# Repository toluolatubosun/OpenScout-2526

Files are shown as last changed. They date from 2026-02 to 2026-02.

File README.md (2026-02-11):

# OpenScout v1.2

OpenScout v1.2 presents an enhanced implementation of the OpenScout mobile robot platform, featuring a novel multi-modal control architecture that integrates conventional wireless control with ROS 2 infrastructure. The system employs a dual-microcontroller architecture utilizing Arduino GIGA R1 WiFi and Arduino Uno, providing three independent control interfaces: HC-12 long-range wireless keypad (100m range),
USB serial interface, and ROS 2 integration via TCP/JSON bridge. A
key innovation is the implementation of a lightweight TCP server on the
Arduino GIGA that enables ROS 2 Twist message compatibility without requiring ros_serial, addressing the compatibility gap in ROS 2 for
resource-constrained embedded systems. The platform incorporates realtime obstacle detection using four ultrasonic sensors with 50cm threshold triggering and buzzer warning with automatic motion prevention.
FreeRTOS task scheduling enables concurrent execution of motor control, network communication, and sensor processing. Quantitative evaluation demonstrates successful multi-modal operation with network latency under 100ms and reliable obstacle detection. This work provides a
reproducible, open-source educational platform bridging embedded systems and modern robotics middleware, licensed under CERN-OHL-S2.0, with complete build documentation enabling 6–20 hour assembly by
non-specialists.

## Demo video can be found in the base of the repository: [Demonstration Video](Demonstration%20Video.mp4)
| | |
|--|--|
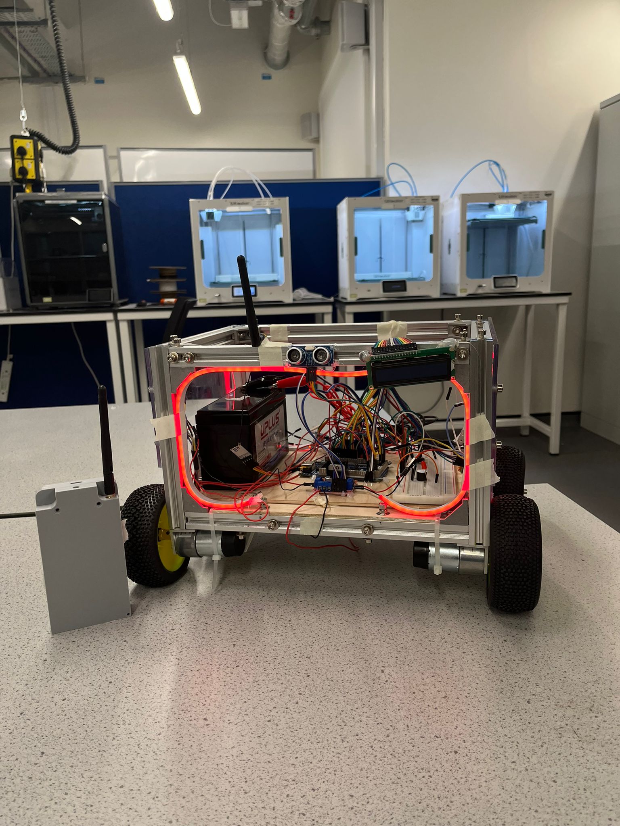
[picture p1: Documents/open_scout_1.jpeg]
OpenScout Robot View 1
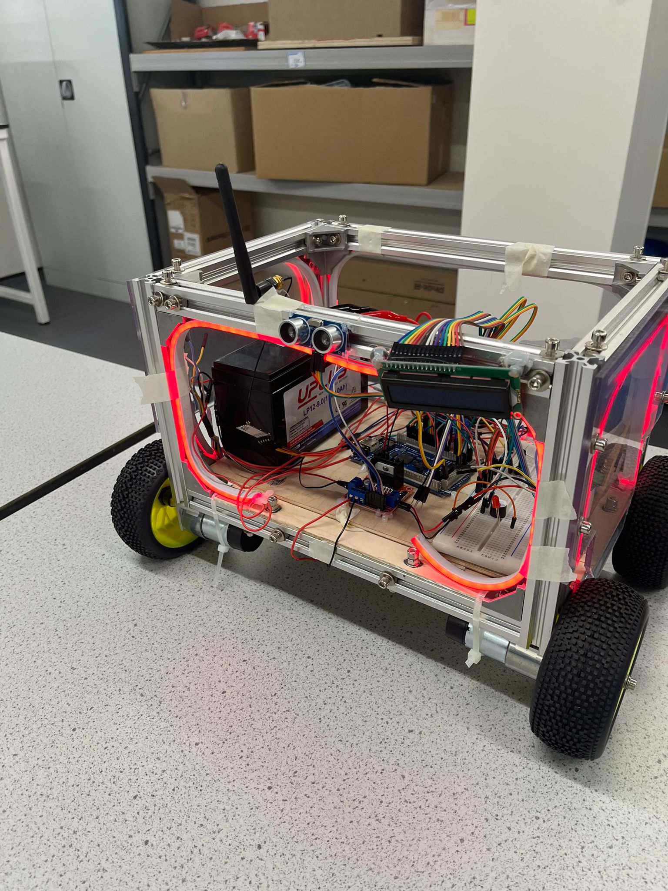
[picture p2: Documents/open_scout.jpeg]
OpenScout Robot View 2
|  |  |
---

## Table of Contents

1. [General Info](#1-general-info)
2. [Build Materials](#2-build-materials)
3. [Mechanical Assembly](#3-mechanical-assembly)
4. [Electric Circuit & Firmware](#4-electric-circuit--firmware)
5. [Testing](#5-testing)
6. [Contributors](#6-contributors) 
7. [Demonstration Video](#7-demonstration-video) 

### 1. General Info 

I. OpenScout V2 & ROS 2 Integration

OpenScout V2 is an enhanced mobile robot platform designed to bridge embedded systems and ROS 2 for accessible robotics education. The system integrates low-level microcontroller-based control with high-level Robot Operating System 2 (ROS 2) infrastructure, enabling both manual and autonomous operation. The platform emphasizes modularity, low cost, and compatibility with resource-constrained embedded hardware.

The robot employs a dual-microcontroller architecture consisting of an Arduino GIGA R1 WiFi and an Arduino Uno. This architecture allows separation of concerns between real-time motor control, sensor processing, and high-level communication with ROS 2. OpenScout V2 supports multiple control interfaces, including wireless, USB serial, and ROS 2-based control.

II. Software Description

OpenScout V2 uses a hybrid software stack combining embedded firmware and ROS 2 middleware. ROS 2 serves as the high-level communication and control framework, while the microcontrollers handle low-level actuation and sensing tasks. ROS 2 operates as a distributed middleware system based on publish–subscribe communication. Motion commands are transmitted as standard ROS 2 messages over a TCP/IP network, allowing seamless integration with existing ROS 2 tools and algorithms. A key design contribution of OpenScout V2 is the implementation of a lightweight TCP/JSON bridge, enabling ROS 2 communication without relying on ros_serial, which is not fully compatible with ROS 2 on constrained embedded platforms.

a). Motion Control

OpenScout V2 is a differential-drive mobile robot. High-level motion commands are expressed using the standard ROS 2 Twist message type, which includes linear and angular velocity components.The Arduino GIGA R1 WiFi hosts a custom TCP server that receives serialized Twist commands from ROS 2 and converts them into motor control signals. These commands are forwarded to the Arduino Uno, which directly controls the motor drivers. This separation ensures real-time responsiveness while maintaining ROS 2 compatibility.

b). Teleoperation Modes

The platform supports multiple manual control modes:

* Wireless keypad control using an HC-12 long-range wireless module (up to 100 m range)

* USB serial control for direct wired operation

* ROS 2 teleoperation, where motion commands are generated from standard ROS 2 tools

>> These interfaces operate independently, enabling flexible switching between control modes for testing, education, and deployment.

c). Sensors and Obstacle Detection

OpenScout V2 is equipped with four ultrasonic distance sensors mounted around the robot chassis. These sensors provide real-time obstacle detection with a configurable threshold (default set to 50 cm).

When an obstacle is detected within the threshold:

* A buzzer warning is triggered

* Robot motion is automatically inhibited to prevent collisions

>>Sensor processing is handled locally on the microcontroller to ensure fast response times independent of ROS 2 network latency.

d). Real-Time Embedded Scheduling

The embedded software stack uses FreeRTOS to manage concurrent tasks on the Arduino GIGA R1 WiFi. Separate tasks are assigned for:

* Motor control

* Network communication (TCP server)

* Sensor acquisition and obstacle detection

>>This task-based scheduling ensures reliable real-time performance and prevents blocking behavior during communication or sensing operations.

e). ROS 2 Communication Interface

Instead of using ros_serial, OpenScout V2 implements a custom TCP-based communication layer. The Arduino GIGA R1 WiFi runs a lightweight TCP server that:

* Receives ROS 2 Twist messages encoded in JSON

* Decodes and validates incoming commands

* Forwards control signals to the motor controller

>>This approach reduces system complexity and improves compatibility with ROS 2, while maintaining low communication latency (measured under 100 ms in evaluation).

---
---
### 2. Build Materials

| Material/Components | Quantity | Reference/Description | Link |
| --- | --- | --- | --- |
| 300 mm 20×20 Aluminium Extrusion | 4 | A1 | [Link](https://ooznest.co.uk/product/v-slot-linear-rail-20x20mm-cut-to-size/) |
| 200 mm 20×20 Aluminium Extrusion | 8 | A2 | [Link](https://ooznest.co.uk/product/v-slot-linear-rail-20x20mm-cut-to-size/) |
| 20×20 Angle Joint Brackets | 16 | B1 | [Link](https://amz.run/5TF6) |
| 90° Cast Corner Brackets | 8 | B2 | [Link](https://ooznest.co.uk/product/90-degree-cast-corner/) |
| M5 × 12 mm Hex Socket Screws | 72 | S5.12 | – |
| M4 T-Slot Nuts | 8 | T4 | – |
| M5 T-Slot Nuts | 72 | T5 | – |
| M5 Washers | 80 | N3 | – |
| Arduino GIGA R1 WiFi | 1 | Main robot controller (receiver) | [Link](https://www.amazon.co.uk/Arduino-Giga-R1-WiFi-ABX00063/dp/B0BTTRZ9TB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) |
| Arduino Uno | 1 | Remote controller (transmitter) | [Link](https://www.amazon.co.uk/Arduino-A000066-ARDUINO-UNO-REV3/dp/B008GRTSV6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) |
| L298N Motor Driver | 2 | Dual H-bridge motor driver for DC motors | [Link](http://amazon.co.uk/CRGANGZY-Development-Electronic-Components-capacitor/dp/B0D6GWW7W6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) |
| DC Gear Motors | 4 | Left and right drive motors | [Link](https://www.amazon.co.uk/CQRobot-Ocean-6V-5W-60RPM-18-oz-12V-10W-120RPM-32/dp/B08ZK8RWK4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,aps,78&sr=8-1&th=1) |
| 16×2 LCD Display | 1 | Displays IP address and system status | N/A |
| 10 kΩ Potentiometer | 1 | LCD contrast adjustment | N/A |
| HC-12 Wireless Module | 2 | Long-range serial wireless communication | [Link](https://www.amazon.co.uk/Wireless-Transceiver-Communication-Transmission-Bluetooth/dp/B07YJDRW6V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) |
| 4×4 Matrix Keypad | 1 | Remote control input interface | N/A |
| 220 Ω Resistor | 1 | LCD backlight current limiting | N/A |
| 12 V Power Supply / Battery | 1 | Powers motors, leds, and Giga R1 | [Link](https://www.amazon.co.uk/UPLUS-LP12-9-Rechargeable-Compatible-Batteries/dp/B0D31M7PKH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) |
| BreadBoard | - | Used to extend the connections from arduino | N/A |
| Jumpers/Wires | - | Connection between components | N/A |
| Vero Board | - | LED controller | [Link](https://www.amazon.co.uk/Electronics%C2%AE-PROTOTYPING-Copper-STRIPBOARD-Circuit/dp/B083ZGMSJX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) |
| Mosfets (P75NF758) | 4 | Control the high voltage leds | [Link](https://www.amazon.co.uk/STP75NF75B-P75N75B-P75NF758-STP75NF758-75NF75/dp/B09PY4KBNT) |
| LED Strip | 1 | 12V LED that can be segmented | - |

*Note: *The items whose corresponding links are N/A are most probably included as Arduino starter kit items or can be found at fabrication lab. Arduino starter kit link: [Starter kit Arduino](https://www.amazon.co.uk/Project-Starter-Tutorial-Prototype-Expansion/dp/B01D8KOZF4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)*

---
---
### 3. Mechanical Assembly

I. Open Scout main assembly

The document produced previously for the open scout Lazy susan bearing version instruction manual should be useful for construction of the cuboid, the back wheels can be added similar to the front wheels (refer to the source files).

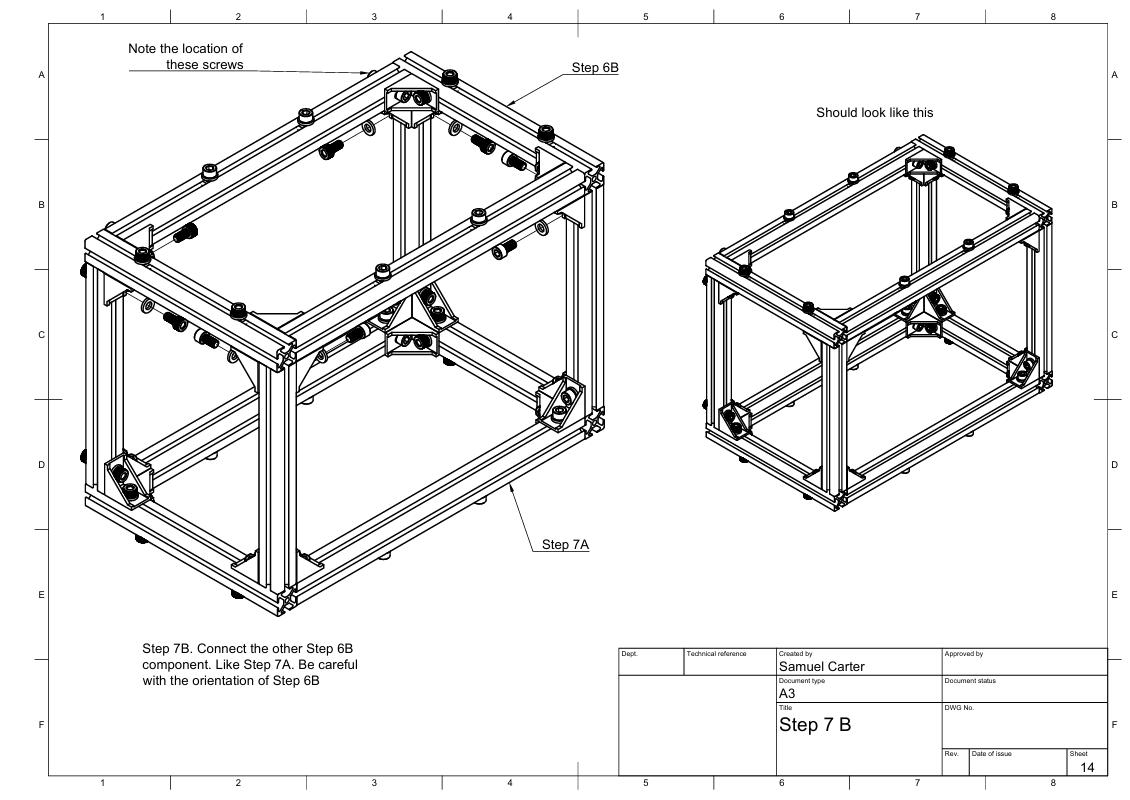
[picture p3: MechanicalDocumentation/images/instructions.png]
Mechanical Assembly Instructions


>>Note: *The size of the openscout is reduced so fewer steps needed to be followed from the main instruction version* 

[Mechanical assembly based on previous version (reduced version)](MechanicalDocumentation/build/InstructionManual.pdf)

Source: [Link to main manual](https://github.com/garry-clawson/OpenScout/tree/main/Hardware/robot_with_lazy_susan_bearing)

II. Wireless Long range enclosure

The wireless transmitter needs to be assembled using the 3D printed parts that can be reproduced using the CAD files which are linked to the repo. The remote assembly should be similar to the one shown in the figure below.

| | |
|--|--|
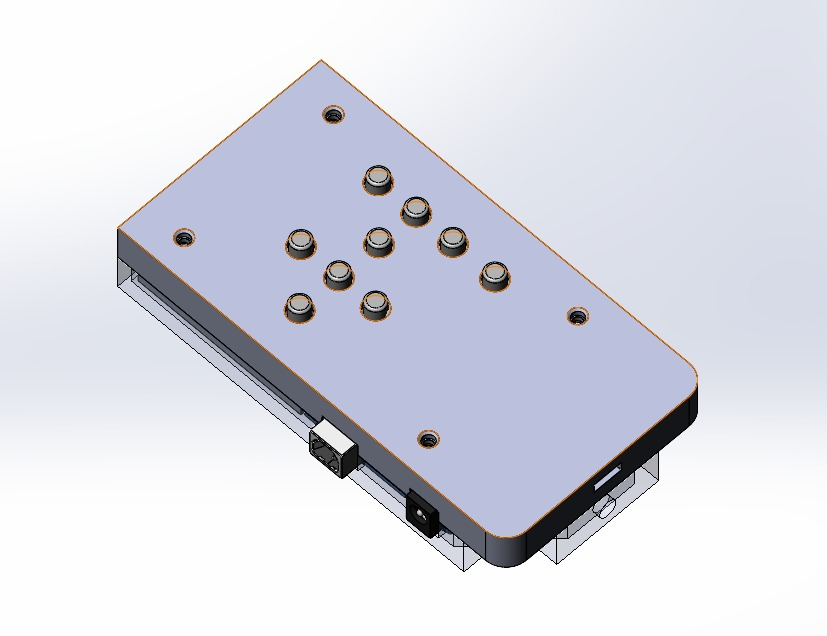
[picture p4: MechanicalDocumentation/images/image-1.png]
Wireless Transmitter Assembly 1
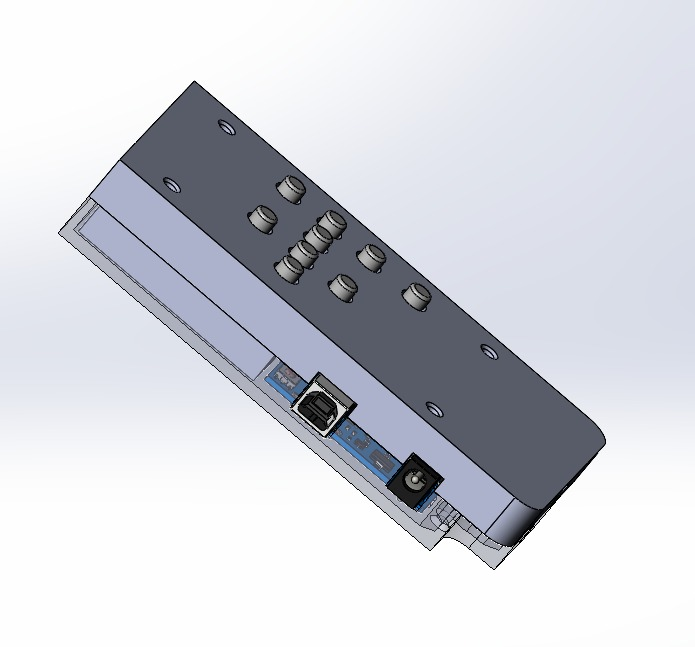
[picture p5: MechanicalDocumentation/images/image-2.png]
Wireless Transmitter Assembly 2
|  |  |
---

[wireless enclosure CAD files](MechanicalDocumentation/remote/)

---
---

### 4. Electric Circuit & Firmware

The main components used in the assembly are the motors driver running the motors, doing the heavy work for the arduino Giga which is configured for the RTOS, for the wireless connections two options exist for which the setup is needed to be done for the HC-12 wireless module.

(Note: Setup the libraries on the Arduino IDE before uploading the firmware) 
[Arduino Libraries](ElectricalDocumentation/library_setup.md)

I. Motor Driver PinOuts (LN298N)

Motor Driver Image

Source: [Motor Driver Pinout Link](https://components101.com/modules/l293n-motor-driver-module)

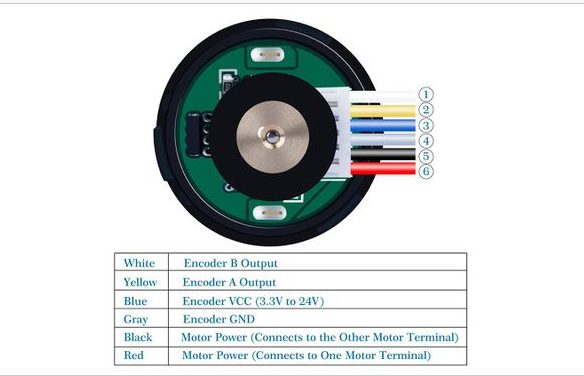
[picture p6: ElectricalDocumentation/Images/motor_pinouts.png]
Motor Driver Pinout Image


Source: [Motor PinOut Connections (Power & Encoder)](http://www.cqrobot.wiki/index.php/DC_Gearmotor_SKU:_CQR37D)

II. OpenScout — Wiring connection guide

The schematic for the openscout can be used as an reference for building/connecting the components:

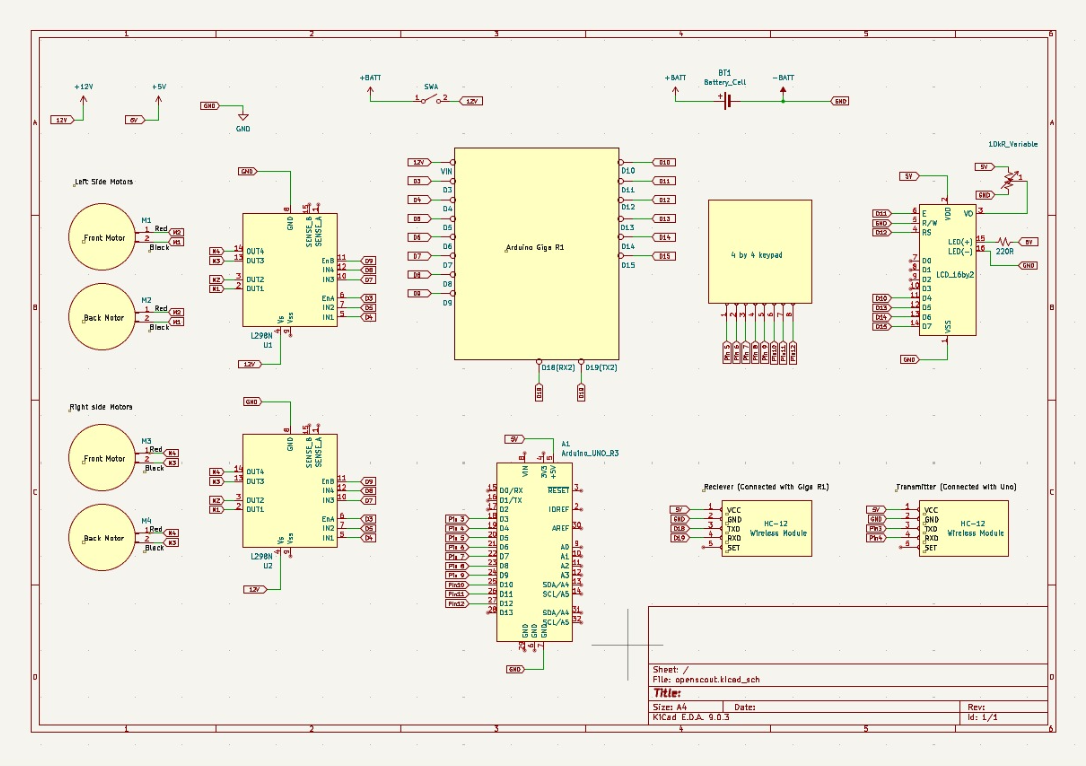
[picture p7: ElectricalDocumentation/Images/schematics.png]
OpenScout Wiring Schematic


---

a). Hardware Overview

This OpenScout robot uses **two Arduino boards**:

1. **Arduino GIGA R1 WiFi** — Main robot controller (receiver)  
2. **Arduino Uno** — Wireless remote control (transmitter)

---

### Step 1: Hardware Assembly

**Robot / Robot Controller (Arduino GIGA R1 WiFi)**

#### Motor Driver Connections (L298N)

**Motor A (Left Motor):**

- Arduino  **D3** → L298N **EN A (PWM)**
- Arduino  **D4** → L298N **IN1**
- Arduino  **D5** → L298N **IN2**

**Motor B (Right Motor):**

- Arduino  **D9** → L298N **EN B (PWM)**
- Arduino  **D7** → L298N **IN3**
- Arduino  **D8** → L298N **IN4** 

#### LCD Display Connections (16×2 LCD)

Connect the LCD to the Arduino GIGA:

- **VSS** → GND  
- **VDD** → **5V**  
- **V0** → center pin of a 10 kΩ potentiometer (for contrast)  
  - Potentiometer other pins: **5V** and **GND**  
- **RS** →  **D12**  
- **RW** → GND  
- **E** →  **D11**  
- **D4** →  **D10**  
- **D5** →  **D13**  
- **D6** →  **D14**  
- **D7** →  **D15**  
- **A (backlight +)** → 5V via **220 Ω resistor**  
- **K (backlight −)** → GND

> The LCD displays the Arduino’s IP address when connected to WiFi and remains blank when not connected.

#### HC-12 Wireless Module (Receiver)

Connect as follows:

- **HC-12 VCC** → 5V  
- **HC-12 GND** → GND  
- **HC-12 TXD** →  **D18 (RX2)**  
- **HC-12 RXD** →  **D19 (TX2)**  
- **HC-12 SET** → *Leave unconnected (normal mode)*  

> **The GIGA uses hardware Serial2 on D18/D19.**

#### Power Connections

- **L298N 12V input** → 12V power supply  
- **L298N GND** ↔ Arduino GIGA **GND** (common ground)  
- **Arduino GIGA** → USB or external power supply

### Membrane Switch Module (Emergency Stop)

Connect:

- **Signal** →  **D2**  
- **VCC** → 5V  
- **GND** → GND  

> **Internal pull-up resistor (goes LOW when pressed).**

---

### Step 2: Configure WiFi Settings

1. Open `wifi_manager.cpp` in the Arduino IDE  
2. Set your WiFi network credentials:  
   - `WIFI_SSID` → your network name  
   - `WIFI_PASSWORD` → your network password  
3. Ensure your computer is on the same WiFi network during setup.

---

### Step 3: Upload Robot Controller Code

1. Open `OpenScoutArduinoCode/OpenScoutArduinoCode.ino`  
2. In the Arduino IDE:  
   - **Tools → Board:** select **Arduino GIGA R1 WiFi**  
   - **Tools → Port:** choose the correct port  
3. Click **Upload**  
4. Open **Serial Monitor** at **9600 baud** to see:  
   - WiFi connection status  
   - Arduino’s IP address (shown on LCD)  
   - HC-12 receiver status

---

### Step 4: (Optional) Start ROS Bridge or setup the wireless 

[Wireless transmitter reciever code (Optional)](ElectricalDocumentation/circuit_assembly_wireless.md)

1. Use Docker Compose to start the ROS bridge:  
   ```bash
   cd OpenScoutROS
   docker-compose build
   docker-compose run ros python3 /app/ros_bridge.py YOUR_ARDUINO_IP

---
---

### 5. Testing

Testing of OpenScout v1.2 is performed incrementally, starting from basic electrical verification and progressing toward full system-level validation. This staged approach helps isolate faults early and ensures safe operation of the platform.

---

### 5.1 Pre-Power Electrical Testing (Continuity & Shorts)

Before applying power, all electrical connections must be verified using a **digital multimeter**.

#### a) Continuity Testing

Use the multimeter in **continuity mode** to verify:

- Ground (GND) continuity across:
  - Arduino GIGA
  - L298N motor drivers
  - Power supply negative terminal
- Signal wire continuity between:
  - Arduino pins and corresponding motor driver inputs
  - Ultrasonic sensor pins and Arduino headers
  - HC-12 TX/RX connections

**Expected result:**
- Multimeter beeps when probes touch both ends of the same connection
- No intermittent or unstable readings

---

### 5.2 Microcontroller Bring-Up Test

#### a) Arduino GIGA R1 WiFi

- Upload a basic LED blink or serial output test
- Verify:
  - Successful power-up
  - Stable serial communication
  - LCD initialization and status display

#### b) Arduino Uno (Remote Controller)

- Upload keypad test firmware
- Verify:
  - Correct keypress detection
  - HC-12 module transmission

---

### 5.3 Wireless Communication Testing (HC-12)

Wireless communication is tested independently prior to motion integration.

Procedure:
1. Upload receiver firmware to Arduino GIGA
2. Upload transmitter firmware to Arduino Uno
3. Send known commands from the keypad
4. Monitor received data via serial output

**Expected result:**
- Correct command reception
- No packet loss at short range
- Stable communication up to ~100 m (line of sight)

---

### 5.4 Motor Driver and Actuation Testing

Motors are tested with the robot **elevated from the ground**.

Procedure:
1. Issue low-speed motion commands
2. Test motors independently
3. Verify:
   - Correct rotation direction
   - PWM speed control
   - Immediate stop on command release

**Expected result:**
- Smooth motor response
- No excessive vibration
- No overheating of L298N drivers

---

### 5.5 Sensor Validation (Ultrasonic Sensors)

Each ultrasonic sensor is tested individually.

Procedure:
- Place obstacles at known distances (20 cm, 50 cm, 100 cm)
- Observe distance measurements via serial output

**Expected result:**
- Measurement accuracy within ±2–3 cm
- Obstacle threshold triggers at ~50 cm
- Buzzer activates upon threshold violation

---

### 5.6 Obstacle Avoidance Safety Test

With motors enabled and robot elevated:

1. Introduce an obstacle within sensor range
2. Observe system response

**Expected result:**
- Immediate buzzer activation
- Motion commands overridden
- Robot motion inhibited until obstacle is removed

---

### 5.7 FreeRTOS Task Stability Test

To validate real-time task scheduling:

- Operate the system continuously for ≥30 minutes
- Monitor:
  - Motor responsiveness
  - Sensor update consistency
  - Network communication stability

**Expected result:**
- No task starvation
- No watchdog resets
- Stable concurrent execution

---

### 5.8 ROS 2 Communication and Latency Testing

Using the ROS 2 TCP/JSON bridge:

1. Publish `cmd_vel` messages from ROS 2
2. Measure command response latency

**Expected result:**
- End-to-end latency below 100 ms
- No dropped motion commands
- Smooth ROS 2 teleoperation

---

### 5.9 System-Level Integration Test

Final validation is performed with the robot operating on the ground:

- Manual wireless control
- USB serial control
- ROS 2 teleoperation

**Expected result:**
- Seamless switching between control modes
- Safe operation under obstacle conditions
- Consistent behavior across all interfaces

---

### 6. Contributors

This project was developed by:

- Ebohon Edosa
- Olatubosun John
- Omar Serag
- Saarunathan Thuvipraksh
- Md Umar Ibrahim
- Muhammad Haroon Javed
- Hasnain Munir
- Abdul Muhaimin
- Olatunji Jeremiah Sodiq
- Obinna Ekoh

---

### 7. Demonstration Video

Watch the demonstration video to see OpenScout in action:

<video src="Demonstration Video.mp4" controls width="600"></video>

---

### 8. References

OpenScout previous versions: 
[Link1](https://github.com/ahmed-elbary/OpenScout), [Link2](https://github.com/ilovemicroplastics/OpenScoutV1-1?tab=readme-ov-file), [Link3](https://github.com/garry-clawson/OpenScout)

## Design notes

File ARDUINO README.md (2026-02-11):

# OpenScout Robot - Arduino Setup Guide

Simple dual-motor robot with FreeRTOS control, LCD display, wireless HC-12 control, and emergency stop.

## Hardware Overview

This project uses **TWO Arduino boards**:
1. **Arduino GIGA R1 WiFi** - Main robot controller (receiver)
2. **Arduino Uno** - Wireless remote control (transmitter)

---

## Step 1: Hardware Assembly

### Robot / Robot Controller (Arduino GIGA R1 WiFi)

#### Motor Driver Connections (L298N)

**Motor A (Left Motor)**
- Arduino Pin 3 → L298N EN A (PWM)
- Arduino Pin 4 → L298N IN1
- Arduino Pin 5 → L298N IN2

**Motor B (Right Motor)**
- Arduino Pin 9 → L298N EN B (PWM)
- Arduino Pin 7 → L298N IN3
- Arduino Pin 8 → L298N IN4

**Motor C (Front-Left Motor)**
- Arduino Pin 2 → L298N EN C (PWM)
- Arduino Pin 22 → L298N IN5
- Arduino Pin 24 → L298N IN6

**Motor D (Front-Right Motor)**
- Arduino Pin 6 → L298N EN D (PWM)
- Arduino Pin 28 → L298N IN7
- Arduino Pin 30 → L298N IN8

#### LCD Display Connections (16x2 LCD)

Connect the 16x2 LCD to Arduino GIGA:

- VSS → GND
- VDD → 5V
- V0 → 10kΩ potentiometer center pin (for contrast adjustment)
  - Potentiometer: One end to 5V, other end to GND
- RS → Pin 12
- RW → GND
- E → Pin 11
- D4 → Pin 10
- D5 → Pin 13
- D6 → Pin 14
- D7 → Pin 15
- A (backlight +) → 5V through 220Ω resistor
- K (backlight -) → GND

**Function:** The LCD displays the Arduino's IP address when WiFi is connected. The screen remains blank when WiFi is disconnected.

#### Ultrasonic Sensors

Connect ultrasonic sensors for obstacle detection:

**Front Ultrasonic Sensor**
- Trig → Pin 50
- Echo → Pin 52
- VCC → 5V
- GND → GND

**Back Ultrasonic Sensor**
- Trig → Pin 36
- Echo → Pin 38
- VCC → 5V
- GND → GND

**Function:** Sensors detect obstacles within 30cm range to prevent collisions.

#### Buzzer

Connect buzzer for audio feedback:
- Buzzer Signal → Pin 34
- VCC → 5V
- GND → GND

**Function:** Beeps for alerts or notifications.

#### LEDs

Connect four indicator LEDs:
- LED1 → Pin 47
- LED2 → Pin 49
- LED3 → Pin 51
- LED4 → Pin 53
- All LEDs: VCC → 5V through 220Ω resistor, GND → GND

**Function:** Visual indicators for system status or events.

#### HC-12 Wireless Module (Receiver)

Connect HC-12 to Arduino GIGA:
- HC-12 VCC → 5V
- HC-12 GND → GND
- HC-12 TXD → Pin D18 (RX2)
- HC-12 RXD → Pin D19 (TX2)
- HC-12 SET → Leave unconnected (normal mode)

**Note:** The GIGA uses hardware Serial2 on pins D18/D19.

#### Power
- L298N 12V input → 12V power supply
- L298N GND → Arduino GIGA GND (common ground)
- Arduino GIGA → USB or separate power supply

---

### Remote Control (Arduino Uno - Transmitter)

#### HC-12 Wireless Module (Transmitter)

Connect HC-12 to Arduino Uno:
- HC-12 VCC → 5V
- HC-12 GND → GND
- HC-12 TXD → Pin 3 (SoftwareSerial RX)
- HC-12 RXD → Pin 4 (SoftwareSerial TX)
- HC-12 SET → Leave unconnected (normal mode)

**Note:** The Uno uses SoftwareSerial on pins 3/4.

#### 4x4 Matrix Keypad

Connect to Arduino Uno:
- **Row pins:** 5, 6, 7, 8
- **Column pins:** 9, 10, 11, 12

#### Membrane Switch Module (Emergency Stop)

Connect to Arduino Uno:
- Signal → Pin 2
- VCC → 5V
- GND → GND

**Note:** Uses internal pull-up resistor (goes LOW when pressed).

#### Power
- Arduino Uno → USB or 5V supply

---

## Step 2: Upload Transmitter Code (Remote Control)

**Upload to Arduino Uno:**

1. Open `OpenScoutTransmitterCode/OpenScoutTransmitterCode.ino`
2. Select **Tools → Board → Arduino Uno**
3. Select your COM port
4. Click **Upload**
5. Open Serial Monitor (9600 baud) to verify transmission

**Remote Keypad Controls:**
- **2** = Forward
- **8** = Backward
- **4** = Turn Left
- **6** = Turn Right
- **5** = Stop
- **A** = Increase Speed (+25 PWM)
- **B** = Decrease Speed (-25 PWM)
- **C** = Increase Duration (+100ms)
- **D** = Decrease Duration (-100ms)
- **Membrane Switch** = Emergency Stop

---

## Step 3: Configure WiFi Settings

1. Open `wifi_manager.cpp` file
2. Update WiFi credentials:
   - Change `WIFI_SSID` to your network name
   - Change `WIFI_PASSWORD` to your network password
3. **Important**: Connect your PC to the same WiFi network

---

## Step 4: Install Arduino IDE Libraries

1. Open Arduino IDE
2. Go to **Tools → Manage Libraries**
3. Search for and install:
   - **ArduinoJson** version **7.4.2**
   - **LiquidCrystal by Arduino** version **1.0.7**
   - **Keypad by Mark Stanley, Alexander Brevig** version **3.0.0**

---

## Step 5: Upload Robot Code

1. Open `OpenScoutArduinoCode/OpenScoutArduinoCode.ino`
2. Select your board: **Tools → Board → Arduino GIGA R1 WiFi**
3. Select port: **Tools → Port → (your port)**
4. Click **Upload**
5. Open Serial Monitor (9600 baud) to see:
   - WiFi connection status
   - Arduino's IP address (also shown on LCD)
   - HC-12 receiver status

---

## Step 6: Start ROS Bridge

Use the Arduino IP from Serial Monitor in these commands:

**Terminal 1 (Start Bridge):**
```bash
cd OpenScoutROS
docker-compose build
docker-compose run ros python3 /app/ros_bridge.py YOUR_ARDUINO_IP
```

**Terminal 2 (Start Teleop):**
```bash
docker exec -it CONTAINER_ID bash -c "source /opt/ros/humble/setup.bash && ros2 run teleop_twist_keyboard teleop_twist_keyboard"
```

Replace `YOUR_ARDUINO_IP` with the IP shown in Arduino Serial Monitor.
Replace `CONTAINER_ID` with the container ID from Terminal 1.

**Alternatively**: Use the provided `.sh` scripts: `./quick_start.sh` and `./start_teleop.sh`

---

## Control Methods

### 1. HC-12 Wireless Remote (Primary)

Use the 4x4 keypad on the Arduino Uno transmitter:

- **2** = Forward
- **8** = Backward
- **4** = Turn Left
- **6** = Turn Right
- **5** = Stop
- **A** = Increase Speed
- **B** = Decrease Speed
- **C** = Increase Duration
- **D** = Decrease Duration
- **Membrane Switch** = Emergency Stop

**Range:** Approximately 100 meters in open space.

### 2. Serial Monitor (USB Direct)

Open Serial Monitor (9600 baud):

- **W** = Forward
- **S** = Backward  
- **A** = Turn Left
- **D** = Turn Right
- **X** = Stop
- **0-9** = Speed (0=slow, 9=fast)
- **+/-** = Step duration (100-900ms)

### 3. ROS 2 Control (WiFi Network)

Use teleop_twist_keyboard:

- **i** = Forward
- **,** = Backward
- **j** = Turn Left
- **l** = Turn Right
- **k** = Stop
- **q/z** = Increase/Decrease speed

---

## System Status

**Arduino GIGA (Robot):**
- Serial Monitor shows WiFi status, IP address, and all commands
- LCD Display shows IP address when connected (blank when disconnected)

**Arduino Uno (Transmitter):**
- Serial Monitor shows "Sent: X" for each keypad press
- Shows "Emergency button pressed!" when membrane switch activated

---

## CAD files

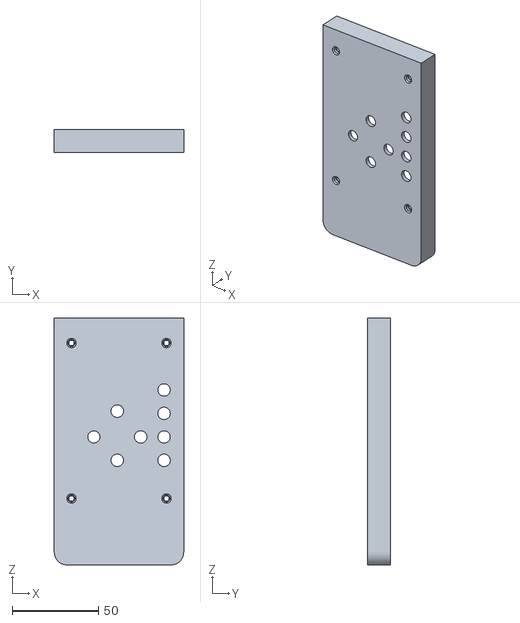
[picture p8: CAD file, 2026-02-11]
MechanicalDocumentation/remote/Body2_with_whole.STL
75.0 x 13.5 x 143.0

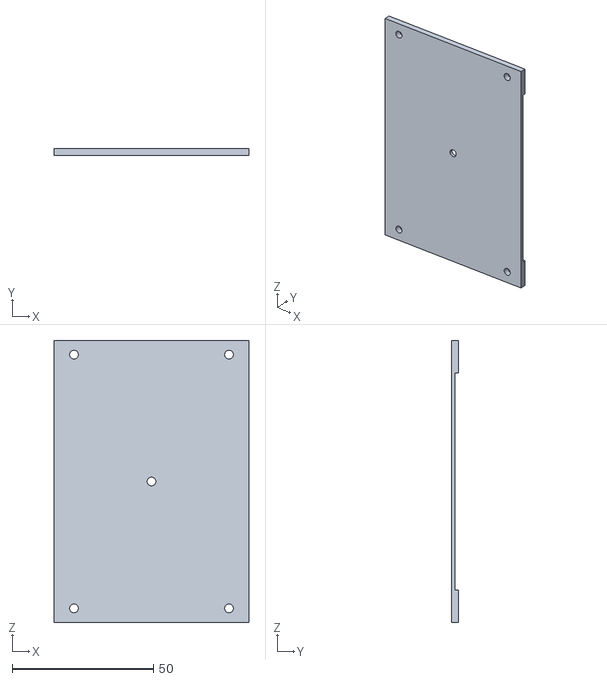
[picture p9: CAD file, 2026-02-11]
MechanicalDocumentation/remote/BAse Plate.STL
69.0 x 2.50 x 100.0

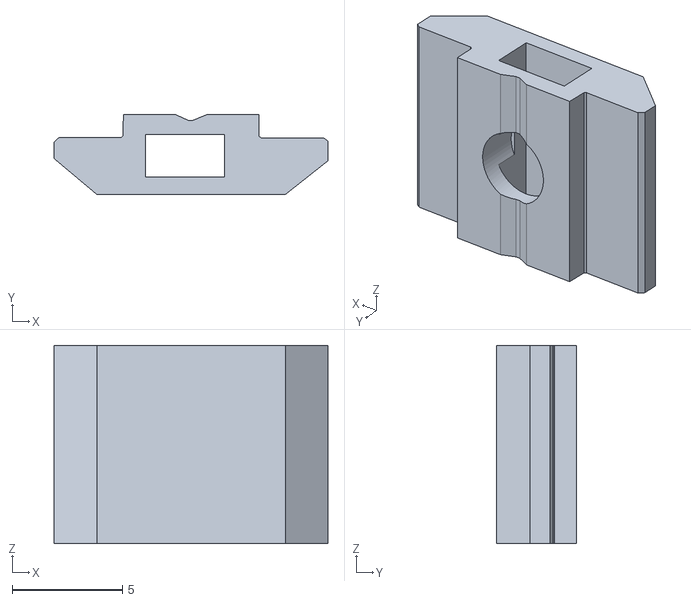
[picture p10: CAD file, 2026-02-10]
OpenScout CAD Files/profile stuff.stl
12.4 x 3.63 x 9.00

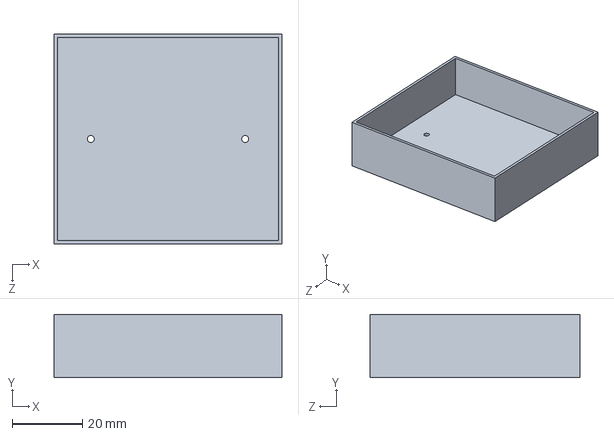
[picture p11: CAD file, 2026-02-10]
Transmitter CAD Files/Battery Case.SLDPRT
65.0 x 18.0 x 60.0 mm

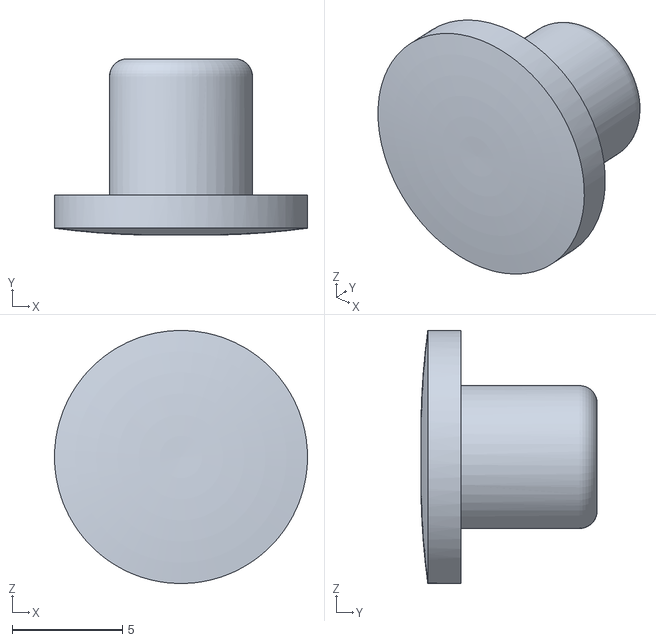
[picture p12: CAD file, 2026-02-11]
MechanicalDocumentation/remote/Button.STL
11.5 x 8.02 x 11.5

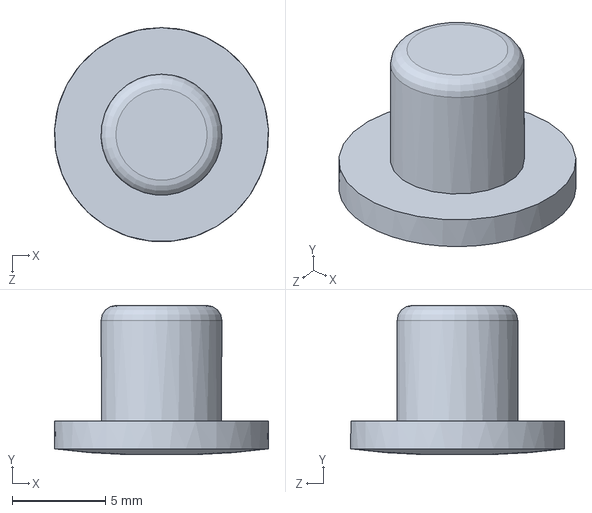
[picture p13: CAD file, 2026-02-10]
Transmitter CAD Files/Button.SLDPRT
11.5 x 8.01 x 11.5 mm

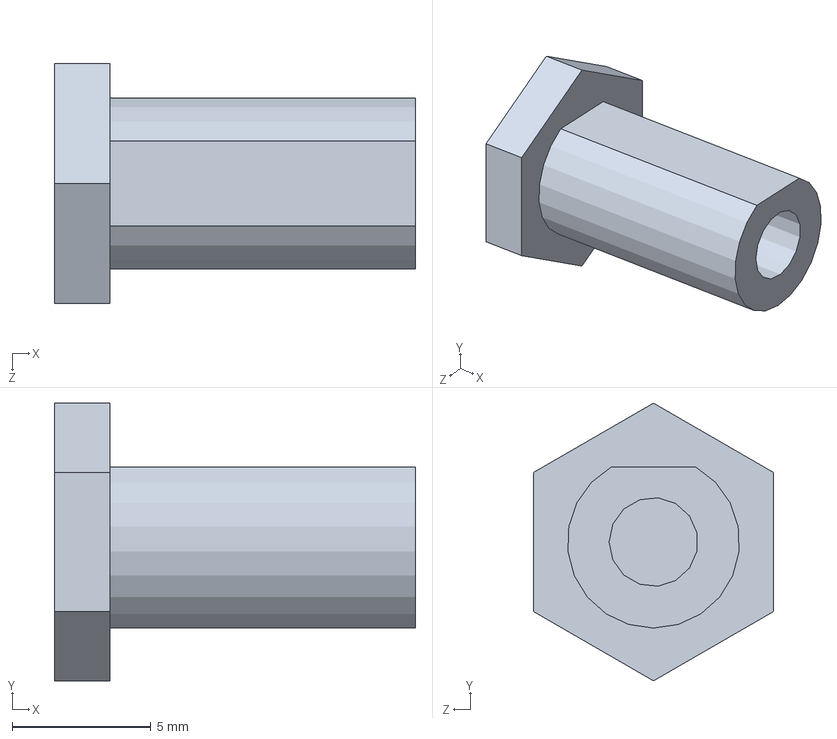
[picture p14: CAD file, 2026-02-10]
Transmitter CAD Files/Thread.SLDPRT
13.0 x 10.0 x 8.66 mm

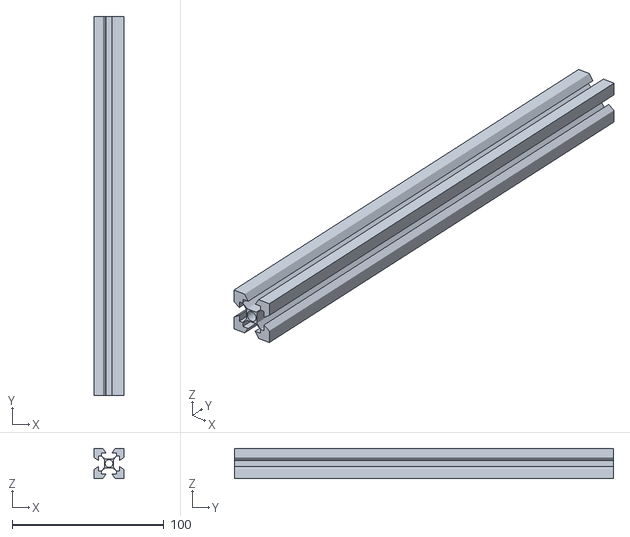
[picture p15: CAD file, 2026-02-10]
OpenScout CAD Files/A2 aluminium.stl
20.0 x 250.0 x 20.0

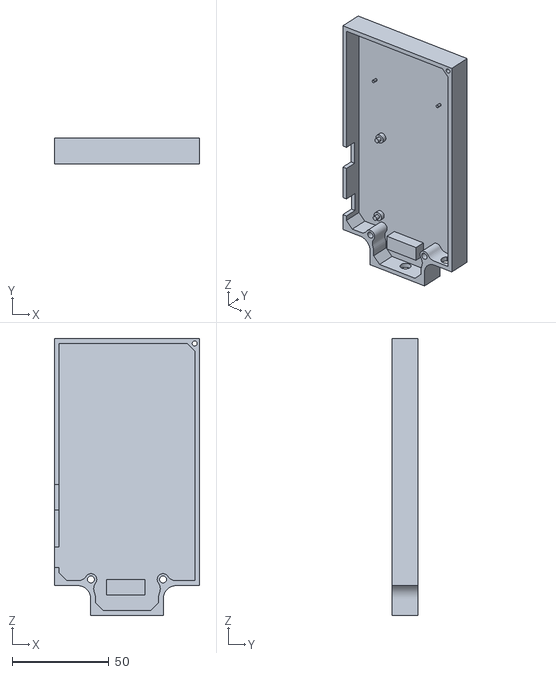
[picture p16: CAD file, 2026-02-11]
MechanicalDocumentation/remote/Body2.STL
75.0 x 13.5 x 143.0

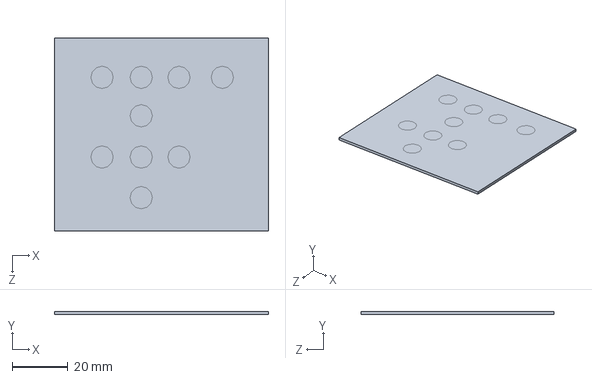
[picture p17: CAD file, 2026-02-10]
Transmitter CAD Files/Touch Pad.SLDPRT
76.5 x 1.20 x 69.1 mm

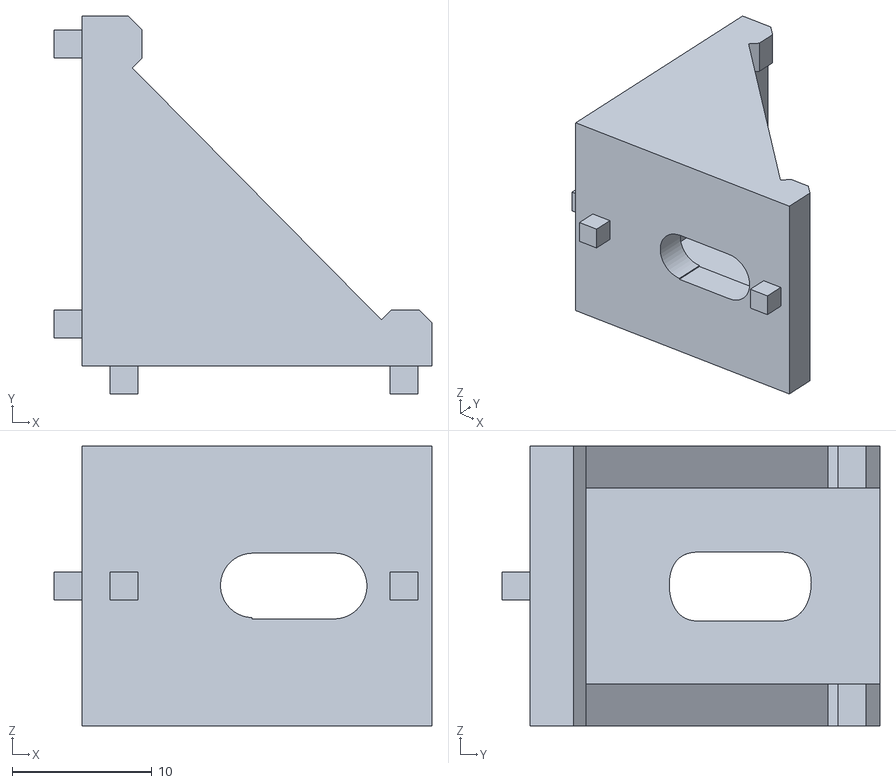
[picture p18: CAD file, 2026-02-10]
OpenScout CAD Files/Angle Bracket 2020.stl
27.0 x 27.0 x 20.0

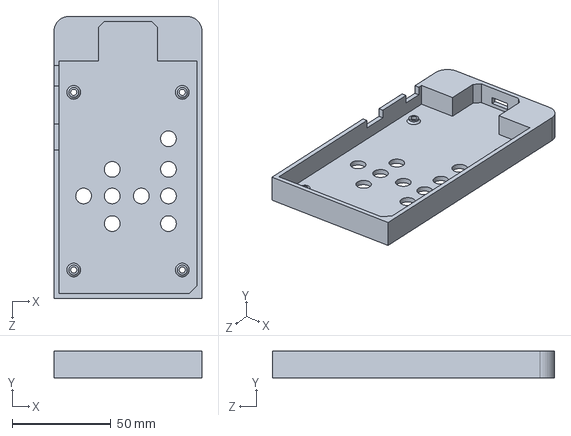
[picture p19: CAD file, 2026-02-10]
Transmitter CAD Files/Body1.SLDPRT
75.0 x 13.5 x 143.0 mm

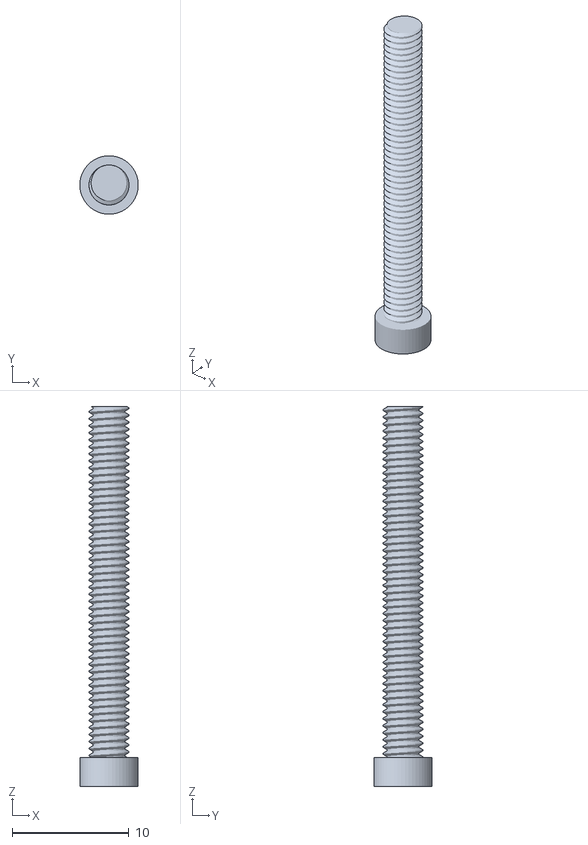
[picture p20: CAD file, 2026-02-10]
OpenScout CAD Files/M4_Screw.stl
4.99 x 5.00 x 32.5

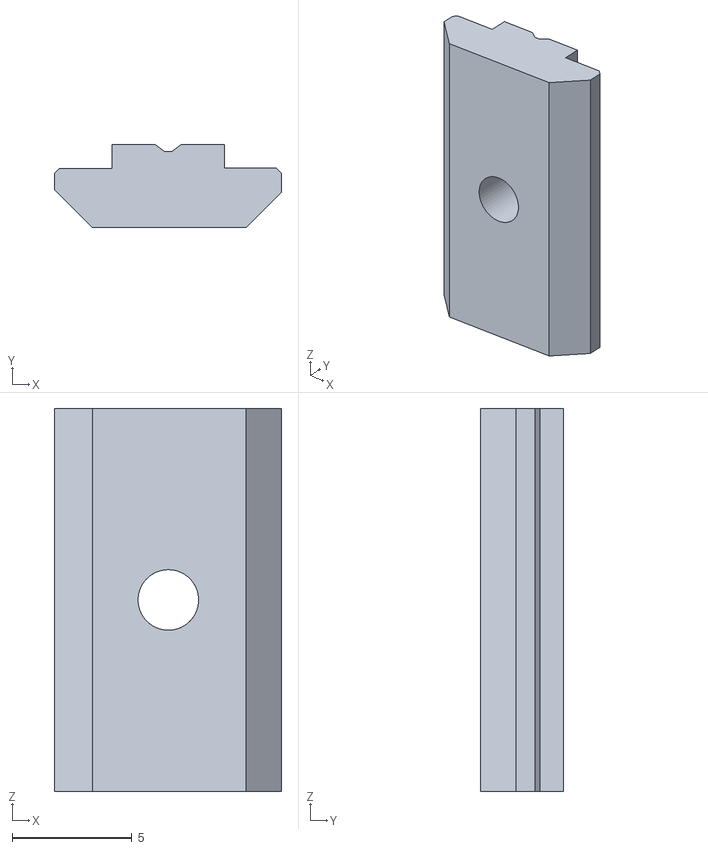
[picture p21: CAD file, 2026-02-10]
OpenScout CAD Files/T-slot_nut_M4.stl
9.48 x 3.48 x 16.0

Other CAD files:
MechanicalDocumentation/remote/Body1.STL
Transmitter CAD Files/BAse Plate.SLDPRT
Transmitter CAD Files/Body2.SLDPRT
OpenScout CAD Files/M4_Screw_(2).stl

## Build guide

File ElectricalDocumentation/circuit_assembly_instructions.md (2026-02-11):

# Circuit Assembly  
*The components required for the circuits assembly are as follows:*

(Note: Setup the libraries on the Arduino IDE) [Arduino Libraries](library_setup.md)

## Motor Driver PinOuts (LN298N)

Motor Driver Image

Source: [Motor Driver Pinout Link](https://components101.com/modules/l293n-motor-driver-module)



Source: [Motor PinOut Connections (Power & Encoder)](http://www.cqrobot.wiki/index.php/DC_Gearmotor_SKU:_CQR37D)

## OpenScout — Wiring connection guide

The schematic for the openscout can be used as an reference for building/connecting the components:



---

## Hardware Overview

This OpenScout robot uses **two Arduino boards**:

1. **Arduino GIGA R1 WiFi** — Main robot controller (receiver)  
2. **Arduino Uno** — Wireless remote control (transmitter)

---

## Step 1: Hardware Assembly

### Robot / Robot Controller (Arduino GIGA R1 WiFi)

#### Motor Driver Connections (L298N)

**Motor A (Left Motor):**

- Arduino  **D3** → L298N **EN A (PWM)**
- Arduino  **D4** → L298N **IN1**
- Arduino  **D5** → L298N **IN2**

**Motor B (Right Motor):**

- Arduino  **D9** → L298N **EN B (PWM)**
- Arduino  **D7** → L298N **IN3**
- Arduino  **D8** → L298N **IN4** 

---

#### LCD Display Connections (16×2 LCD)

Connect the LCD to the Arduino GIGA:

- **VSS** → GND  
- **VDD** → **5V**  
- **V0** → center pin of a 10 kΩ potentiometer (for contrast)  
  - Potentiometer other pins: **5V** and **GND**  
- **RS** →  **D12**  
- **RW** → GND  
- **E** →  **D11**  
- **D4** →  **D10**  
- **D5** →  **D13**  
- **D6** →  **D14**  
- **D7** →  **D15**  
- **A (backlight +)** → 5V via **220 Ω resistor**  
- **K (backlight −)** → GND

> The LCD displays the Arduino’s IP address when connected to WiFi and remains blank when not connected.

---

#### HC-12 Wireless Module (Receiver)

Connect as follows:

- **HC-12 VCC** → 5V  
- **HC-12 GND** → GND  
- **HC-12 TXD** →  **D18 (RX2)**  
- **HC-12 RXD** →  **D19 (TX2)**  
- **HC-12 SET** → *Leave unconnected (normal mode)*  

> **The GIGA uses hardware Serial2 on D18/D19.**

---

#### Power Connections

- **L298N 12V input** → 12V power supply  
- **L298N GND** ↔ Arduino GIGA **GND** (common ground)  
- **Arduino GIGA** → USB or external power supply

---

### Membrane Switch Module (Emergency Stop)

Connect:

- **Signal** →  **D2**  
- **VCC** → 5V  
- **GND** → GND  

> **Internal pull-up resistor (goes LOW when pressed).**

---

## Step 2: Configure WiFi Settings

1. Open `wifi_manager.cpp` in the Arduino IDE  
2. Set your WiFi network credentials:  
   - `WIFI_SSID` → your network name  
   - `WIFI_PASSWORD` → your network password  
3. Ensure your computer is on the same WiFi network during setup.

---

## Step 3: Upload Robot Controller Code

1. Open `OpenScoutArduinoCode/OpenScoutArduinoCode.ino`  
2. In the Arduino IDE:  
   - **Tools → Board:** select **Arduino GIGA R1 WiFi**  
   - **Tools → Port:** choose the correct port  
3. Click **Upload**  
4. Open **Serial Monitor** at **9600 baud** to see:  
   - WiFi connection status  
   - Arduino’s IP address (shown on LCD)  
   - HC-12 receiver status

---

## Step 4: (Optional) Start ROS Bridge or setup the wireless 
[Wireless transmitter reciever code (Optional)](circuit_assembly_wireless.md)

1. Use Docker Compose to start the ROS bridge:  
   ```bash
   cd OpenScoutROS
   docker-compose build
   docker-compose run ros python3 /app/ros_bridge.py YOUR_ARDUINO_IP

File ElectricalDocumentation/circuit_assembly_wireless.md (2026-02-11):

# Wireless transmitter connections setup

## Step 1: Setup Remote Control (Arduino Uno — Transmitter)

### HC-12 Wireless Module (Transmitter)

Connect:

- **HC-12 VCC** → 5V  
- **HC-12 GND** → GND  
- **HC-12 TXD** →  **Pin 3** *(SoftwareSerial RX)*  
- **HC-12 RXD** →  **Pin 4** *(SoftwareSerial TX)*  
- **HC-12 SET** → *Leave unconnected (normal mode)*

---

### 4×4 Matrix Keypad Connections

Connect to Arduino Uno:

- **Row pins:** Pin 5, Pin 6, Pin 7, Pin 8  
- **Column pins:** Pin 9, Pin 10, Pin 11, Pin 12

---

### Power for Transmitter

- **Arduino Uno** → USB or 5V supply

---

## Step 2: Upload Transmitter Code (Remote Control)

1. Open `OpenScoutTransmitterCode/OpenScoutTransmitterCode.ino`  
2. In the Arduino IDE:  
   - **Tools → Board:** select **Arduino Uno**  
   - **Tools → Port:** select the COM port  
3. Click **Upload**  
4. Open **Serial Monitor** at **9600 baud** to verify transmission

**Remote Keypad Controls:**

- **2** = Forward  
- **8** = Backward  
- **4** = Turn Left  
- **6** = Turn Right  
- **5** = Stop  
- **A** = Increase Speed (+25 PWM)  
- **B** = Decrease Speed (−25 PWM)  
- **C** = Increase Duration (+100 ms)  
- **D** = Decrease Duration (−100 ms)  
- **Emergency switch** = Emergency Stop

---

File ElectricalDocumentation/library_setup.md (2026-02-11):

# Install the following libraries 

## The components which are used for the openscout requires external libraries

---

Install the following libraries:

- **ArduinoJson** (version 7.4.2)  
- **LiquidCrystal** (version 1.0.7)  
- **Keypad** by Mark Stanley & Alexander Brevig (version 3.0.0)

---

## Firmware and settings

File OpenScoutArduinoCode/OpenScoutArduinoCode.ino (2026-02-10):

#if defined(ARDUINO_GIGA)
  #define USE_MBED_OS
  #include "mbed.h"
  using namespace rtos;
  using namespace std::chrono;
#else
  #define USE_FREERTOS
  #include <Arduino_FreeRTOS.h>
#endif

#include "tcp_server.h"
#include "wifi_manager.h"
#include "motor_control.h"
#include "hc12_receiver.h"

// === SHARED STATE (Global) ===
MotorCommand currentCommand = {'X', 150, 300, 0};

// Mutex to protect currentCommand from race conditions
#ifdef USE_MBED_OS
  rtos::Mutex commandMutex;
#else
  SemaphoreHandle_t commandMutex;
#endif

// === Helper Functions ===
void updateSpeed(int speedLevel);
void updateDuration(int change);
void printMenu();

// === TASK DECLARATIONS ===
#ifdef USE_FREERTOS
  void TaskSerialRead(void* pvParameters);
  void TaskMotorControl(void* pvParameters);
  void TaskWiFiMonitor(void* pvParameters);
  void TaskTCPServer(void* pvParameters);
  void TaskHC12Read(void* pvParameters);
#else
  void TaskSerialRead();
  void TaskMotorControl();
  void TaskWiFiMonitor();
  void TaskTCPServer();
  void TaskHC12Read();
#endif

// === RTOS THREAD/TASK HANDLES ===
#ifdef USE_MBED_OS
  Thread serialThread;
  Thread motorThread;
  Thread wifiThread;
  Thread tcpThread;
  Thread hc12Thread;
#else
  TaskHandle_t serialTaskHandle;
  TaskHandle_t motorTaskHandle;
  TaskHandle_t wifiTaskHandle;
  TaskHandle_t tcpTaskHandle;
  TaskHandle_t hc12TaskHandle;
#endif

// === RTOS ABSTRACTION LAYER ===
inline void rtos_delay_ms(unsigned long ms) {
  #ifdef USE_MBED_OS
    ThisThread::sleep_for(std::chrono::milliseconds(ms));
  #else
    vTaskDelay(ms / portTICK_PERIOD_MS);
  #endif
}

void rtos_create_tasks() {
  #ifdef USE_MBED_OS
    serialThread.start(TaskSerialRead);
    motorThread.start(TaskMotorControl);
    wifiThread.start(TaskWiFiMonitor);
    tcpThread.start(TaskTCPServer);
    hc12Thread.start(TaskHC12Read);
  #else
    xTaskCreate(TaskSerialRead, "Serial", 256, NULL, 1, &serialTaskHandle);
    xTaskCreate(TaskMotorControl, "Motor", 256, NULL, 1, &motorTaskHandle);
    xTaskCreate(TaskWiFiMonitor, "WiFi", 128, NULL, 1, &wifiTaskHandle);
    xTaskCreate(TaskTCPServer, "TCP", 256, NULL, 1, &tcpTaskHandle);
    xTaskCreate(TaskHC12Read, "HC12", 256, NULL, 1, &hc12TaskHandle);
    vTaskStartScheduler();
  #endif
}

void setup() { 
  Serial.begin(9600);

  initializeMotorPins();
  initializeHC12();

  // Initialize mutex (only needed for FreeRTOS)
  #ifndef USE_MBED_OS
    commandMutex = xSemaphoreCreateMutex();
  #endif

  printMenu();
  initializeWiFi();

  rtos_create_tasks();
}

void loop() {
  // Empty
}

// === SERIAL READING TASK ===
#ifdef USE_FREERTOS
void TaskSerialRead(void* pvParameters) {
#else
void TaskSerialRead() {  
#endif
  while (1) {
    char input = 0;
    String commandSource = "Serial";
    bool commandReceived = false;
    
    // Check serial for commands - read ALL available and keep only the LATEST
    if (Serial.available() > 0) {
      char latestChar = 0;
      
      // Read all buffered characters and keep only the last non-whitespace one
      while (Serial.available() > 0) {
        char c = Serial.read();
        // Skip whitespace but keep the last valid character
        if (c != ' ' && c != '\t' && c != '\n' && c != '\r') {
          latestChar = c;
        }
      }
      
      // Only process if we got a valid character
      if (latestChar != 0) {
        input = latestChar;
        commandReceived = true;
        commandSource = "Serial";
      }
    }

    if (commandReceived) {
      Serial.print(commandSource);
      Serial.print(" Command: ");
      Serial.println(input);
    }
    
    // Process the command if we received one
    if (commandReceived) {
      switch (input) {
        case 'W': case 'w':
          commandMutex.lock();
          currentCommand.cmd = 'W';
          currentCommand.timestamp = millis();
          commandMutex.unlock();
          break;
          
        case 'S': case 's':
          commandMutex.lock();
          currentCommand.cmd = 'S';
          currentCommand.timestamp = millis();
          commandMutex.unlock();
          break;
          
        case 'A': case 'a':
          commandMutex.lock();
          currentCommand.cmd = 'A';
          currentCommand.timestamp = millis();
          commandMutex.unlock();
          break;
          
        case 'D': case 'd':
          commandMutex.lock();
          currentCommand.cmd = 'D';
          currentCommand.timestamp = millis();
          commandMutex.unlock();
          break;
          
        case 'X': case 'x':
          commandMutex.lock();
          currentCommand.cmd = 'X';
          commandMutex.unlock();
          break;

        case '0': case '1': case '2': case '3': case '4':
        case '5': case '6': case '7': case '8': case '9':
          updateSpeed(input - '0');
          break;
          
        case '-':
          updateDuration(-100);
          break;
          
        case '+':
          updateDuration(100);
          break;
      }
    }
    rtos_delay_ms(10);
  }
}

// === MOTOR CONTROL TASK (unchanged) ===
#ifdef USE_FREERTOS
void TaskMotorControl(void* pvParameters) {
#else
void TaskMotorControl() {
#endif
  char lastCmd = '\0';  // Track previous command to avoid repeated printing
  
  while (1) {
    // Read command atomically
    commandMutex.lock();
    MotorCommand cmd = currentCommand;
    commandMutex.unlock();

    unsigned long now = millis();
    if (cmd.cmd != 'X' && (now - cmd.timestamp) >= cmd.duration) {
      commandMutex.lock();
      currentCommand.cmd = 'X';
      commandMutex.unlock();
      cmd.cmd = 'X';
    }
    
    // Check for obstacles before moving forward or backward
    if (cmd.cmd == 'W' && !canMoveForward()) {
      beepBuzzer();  // Beep when obstacle detected
      cmd.cmd = 'X';  // Stop if obstacle in front
    } else if (cmd.cmd == 'S' && !canMoveBackward()) {
      beepBuzzer();  // Beep when obstacle detected
      cmd.cmd = 'X';  // Stop if obstacle in back
    }
    
    // Only print when command changes
    if (cmd.cmd != lastCmd) {
      switch (cmd.cmd) {
        case 'W':
          Serial.println("Moving Forward");
          break;
        case 'S':
          Serial.println("Moving Backward");
          break;
        case 'A':
          Serial.println("Turning Left");
          break;
        case 'D':
          Serial.println("Turning Right");
          break;
        case 'X':
          Serial.println("Stopping Motors");
          break;
      }
      lastCmd = cmd.cmd;
    }
    
    // Always execute the motor commands
    switch (cmd.cmd) {
      case 'W':
        turnOffAllLEDs();
        digitalWrite(led1, HIGH);
        motorAForward();
        motorBForward();
        motorCForward();
        motorDForward();
        break;
      case 'S':
        turnOffAllLEDs();
        digitalWrite(led2, HIGH);
        motorABackward();
        motorBBackward();
        motorCBackward();
        motorDBackward();
        break;
      case 'A':
        turnOffAllLEDs();
        digitalWrite(led3, HIGH);
        motorABackward();
        motorBForward();
        motorCBackward();
        motorDForward();
        break;
      case 'D':
        turnOffAllLEDs();
        digitalWrite(led4, HIGH);
        motorAForward();
        motorBBackward();
        motorCForward();
        motorDBackward();
        break;
      case 'X':
        turnOffAllLEDs();
        stopAllMotors();
        break;
    }
    
    rtos_delay_ms(10);
  }
}

// === WIFI MONITORING TASK ===
#ifdef USE_FREERTOS
void TaskWiFiMonitor(void* pvParameters) {
#else
void TaskWiFiMonitor() {
#endif
  bool tcpInitialized = false;
  
  while (1) {
    bool wifiConnected = (WiFi.status() == WL_CONNECTED);
    
    // If WiFi connected and TCP not initialized
    if (wifiConnected && !tcpInitialized) {
      initializeTCPServer();
      tcpInitialized = true;
    }
    
    // If WiFi disconnected, mark TCP as needing re-init
    if (!wifiConnected && tcpInitialized) {
      Serial.println("WiFi lost - TCP will reinitialize on reconnect");
      tcpInitialized = false;
    }
    
    // Check/reconnect WiFi
    checkConnections();
    
    rtos_delay_ms(15000);  // Check every 15 seconds
  }
}

// === NEW: TCP SERVER TASK ===
#ifdef USE_FREERTOS
void TaskTCPServer(void* pvParameters) {
#else
void TaskTCPServer() {
#endif
  while (1) {
    // Handle incoming TCP connections and commands
    handleTCPClient();
    
    // Send status every 100ms if client connected
    static unsigned long lastStatusTime = 0;
    unsigned long now = millis();
    if (clientConnected && (now - lastStatusTime) >= 100) {
      sendStatusJSON();
      lastStatusTime = now;
    }
    
    rtos_delay_ms(10);
  }
}

// === NEW: HC-12 READING TASK ===
#ifdef USE_FREERTOS
void TaskHC12Read(void* pvParameters) {
#else
void TaskHC12Read() {
#endif
  while (1) {
    handleHC12Commands();
    rtos_delay_ms(10);
  }
}

// === HELPER FUNCTIONS (unchanged) ===
void updateSpeed(int speedLevel) {
  int pwm = map(speedLevel, 0, 9, 50, 255);
  
  commandMutex.lock();
  currentCommand.speed = pwm;
  commandMutex.unlock();
  
  Serial.print("Speed: ");
  Serial.print(speedLevel);
  Serial.print(" (PWM ");
  Serial.print(pwm);
  Serial.println(")");
}

void updateDuration(int change) {
  commandMutex.lock();
  currentCommand.duration += change;
  if (currentCommand.duration < 100) currentCommand.duration = 100;
  if (currentCommand.duration > 900) currentCommand.duration = 900;
  currentCommand.duration = (currentCommand.duration / 100) * 100;
  int dur = currentCommand.duration;
  commandMutex.unlock();
  
  Serial.print("Duration: ");
  Serial.print(dur);
  Serial.println("ms");
}
void printMenu() {
  Serial.println("================================");
  Serial.println("=== Real-Time Motor Control ===");
  Serial.println("W/S = Forward/Backward");
  Serial.println("A/D = Turn Left/Right");
  Serial.println("X = Stop");
  Serial.println("0-9 = Speed");
  Serial.println("+/- = Duration 100-900ms");
  Serial.println("================================");
}

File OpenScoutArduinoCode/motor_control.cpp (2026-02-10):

#include "motor_control.h"
#include <Arduino.h>

#if defined(ARDUINO_GIGA)
  #include "mbed.h"
  using namespace rtos;
#endif

// === MOTOR PIN DEFINITIONS ===
const int enA = 3, in1 = 4, in2 = 5;     // Motor A (Back - Left)
const int enB = 9, in3 = 7, in4 = 8;     // Motor B (Back - Right)
const int enC = 2, in5 = 22, in6 = 24;   // Motor C (Front - Left) - CHANGED
const int enD = 6, in7 = 28, in8 = 30;   // Motor D (Front - Right) - CHANGED

// === ULTRASONIC SENSOR PIN DEFINITIONS ===
const int trigFront = 50, echoFront = 52;  // Front sensor
const int trigBack = 36, echoBack = 38;    // Back sensor

// === BUZZER PIN DEFINITION ===
const int buzzerPin = 34;

// === LED PIN DEFINITIONS ===
const int led1 = 47, led2 = 49, led3 = 51, led4 = 53;

// Access to global command from main file
extern MotorCommand currentCommand;

#if defined(ARDUINO_GIGA)
  extern rtos::Mutex commandMutex;
#else
  extern SemaphoreHandle_t commandMutex;
#endif

// === MOTOR A (LEFT) ===
void motorAForward() {
  commandMutex.lock();
  int speed = currentCommand.speed;
  commandMutex.unlock();
  
  digitalWrite(in1, HIGH);
  digitalWrite(in2, LOW);
  analogWrite(enA, speed);
}

void motorABackward() {
  commandMutex.lock();
  int speed = currentCommand.speed;
  commandMutex.unlock();

  digitalWrite(in1, LOW);
  digitalWrite(in2, HIGH);
  analogWrite(enA, speed);
}

void stopMotorA() {
  digitalWrite(in1, LOW);
  digitalWrite(in2, LOW);
  analogWrite(enA, 0);
}

// === MOTOR B (RIGHT) ===
void motorBForward() {
  commandMutex.lock();
  int speed = currentCommand.speed;
  commandMutex.unlock();
  
  digitalWrite(in4, HIGH);
  digitalWrite(in3, LOW);
  analogWrite(enB, speed);
}

void motorBBackward() {
  commandMutex.lock();
  int speed = currentCommand.speed;
  commandMutex.unlock();
  
  digitalWrite(in4, LOW);
  digitalWrite(in3, HIGH);
  analogWrite(enB, speed);
}

void stopMotorB() {
  digitalWrite(in4, LOW);
  digitalWrite(in3, LOW);
  analogWrite(enB, 0);
}

// === MOTOR C (FRONT - LEFT) ===
void motorCForward() {
  commandMutex.lock();
  int speed = currentCommand.speed;
  commandMutex.unlock();
  
  digitalWrite(in5, HIGH);
  digitalWrite(in6, LOW);
  analogWrite(enC, speed);
}

void motorCBackward() {
  commandMutex.lock();
  int speed = currentCommand.speed;
  commandMutex.unlock();

  digitalWrite(in5, LOW);
  digitalWrite(in6, HIGH);
  analogWrite(enC, speed);
}

void stopMotorC() {
  digitalWrite(in5, LOW);
  digitalWrite(in6, LOW);
  analogWrite(enC, 0);
}

// === MOTOR D (FRONT - RIGHT) ===
void motorDForward() {
  commandMutex.lock();
  int speed = currentCommand.speed;
  commandMutex.unlock();
  
  digitalWrite(in8, HIGH);
  digitalWrite(in7, LOW);
  analogWrite(enD, speed);
}

void motorDBackward() {
  commandMutex.lock();
  int speed = currentCommand.speed;
  commandMutex.unlock();
  
  digitalWrite(in8, LOW);
  digitalWrite(in7, HIGH);
  analogWrite(enD, speed);
}

void stopMotorD() {
  digitalWrite(in8, LOW);
  digitalWrite(in7, LOW);
  analogWrite(enD, 0);
}

// === STOP ALL ===
void stopAllMotors() {
  stopMotorA();
  stopMotorB();
  stopMotorC();
  stopMotorD();
}

// === ULTRASONIC FUNCTIONS ===
long getDistanceFront() {
  digitalWrite(trigFront, LOW);
  delayMicroseconds(2);
  digitalWrite(trigFront, HIGH);
  delayMicroseconds(10);
  digitalWrite(trigFront, LOW);
  long duration = pulseIn(echoFront, HIGH);
  return duration * 0.034 / 2;  // Convert to cm
}

long getDistanceBack() {
  digitalWrite(trigBack, LOW);
  delayMicroseconds(2);
  digitalWrite(trigBack, HIGH);
  delayMicroseconds(10);
  digitalWrite(trigBack, LOW);
  long duration = pulseIn(echoBack, HIGH);
  return duration * 0.034 / 2;  // Convert to cm
}

bool canMoveForward() {
  return getDistanceFront() > 30;  // Threshold: 30cm
}

bool canMoveBackward() {
  return getDistanceBack() > 30;   // Threshold: 30cm
}

// === BUZZER FUNCTION ===
void beepBuzzer() {
  digitalWrite(buzzerPin, HIGH);
  delay(200);  // Beep for 200ms
  digitalWrite(buzzerPin, LOW);
}

// === LED FUNCTIONS ===
void turnOffAllLEDs() {
  digitalWrite(led1, LOW);
  digitalWrite(led2, LOW);
  digitalWrite(led3, LOW);
  digitalWrite(led4, LOW);
}

// === INITIALIZATION ===
void initializeMotorPins() {
  pinMode(enA, OUTPUT);
  pinMode(in1, OUTPUT);
  pinMode(in2, OUTPUT);
  pinMode(enB, OUTPUT);
  pinMode(in3, OUTPUT);
  pinMode(in4, OUTPUT);
  pinMode(enC, OUTPUT);
  pinMode(in5, OUTPUT);
  pinMode(in6, OUTPUT);
  pinMode(enD, OUTPUT);
  pinMode(in7, OUTPUT);
  pinMode(in8, OUTPUT);
  
  // Initialize ultrasonic pins
  pinMode(trigFront, OUTPUT);
  pinMode(echoFront, INPUT);
  pinMode(trigBack, OUTPUT);
  pinMode(echoBack, INPUT);
  
  // Initialize buzzer pin
  pinMode(buzzerPin, OUTPUT);
  
  // Initialize LED pins
  pinMode(led1, OUTPUT);
  pinMode(led2, OUTPUT);
  pinMode(led3, OUTPUT);
  pinMode(led4, OUTPUT);
  
  // Turn LEDs off initially
  turnOffAllLEDs();
  
  stopAllMotors();
}

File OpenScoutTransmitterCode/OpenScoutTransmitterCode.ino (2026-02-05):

#include <SoftwareSerial.h>
#include <Keypad.h>

SoftwareSerial HC12(3, 4); // TX, RX

const byte ROWS = 4;
const byte COLS = 4;
char keys[ROWS][COLS] = {
  {'1','2','3','A'},
  {'4','5','6','B'},
  {'7','8','9','C'},
  {'*','0','#','D'}
};
byte rowPins[ROWS] = {5, 6, 7, 8};
byte colPins[COLS] = {9, 10, 11, 12};

Keypad keypad = Keypad(makeKeymap(keys), rowPins, colPins, ROWS, COLS);

const int buttonPin = 2;

void setup() {
  Serial.begin(9600);
  HC12.begin(9600);
  pinMode(buttonPin, INPUT_PULLUP);
  Serial.println("HC-12 Transmitter Ready");
}

void loop() {
  char key = keypad.getKey();
  
  if (key) {
    HC12.print(key);
    Serial.print("Sent: ");
    Serial.println(key);
  }
  
  if (digitalRead(buttonPin) == LOW) {
    HC12.print("EMERGENCY");
    Serial.println("Emergency button pressed!");
    delay(500);
  }
}

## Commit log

2026-02-02 remove motor connection and e-stop button instructions from README
2026-02-02 optimize motor control task to reduce repeated command printing
2026-02-02 remove e-stop status from Arduino status messages
2026-02-02 add motor C and D control functions; update task creation and pin definitions
2026-02-05 Refactor: Remove TCP server and WiFi manager implementations
    - Deleted tcp_server.cpp and tcp_server.h files, removing TCP server functionality.
    - Removed wifi_manager.cpp and wifi_manager.h files, eliminating WiFi management code.
    - Added new implementations for TCP server and WiFi management in OpenScoutArduinoCode.
    - Introduced HC-12 receiver functionality with new hc12_receiver.cpp and hc12_receiver.h files.
    - Created motor control functions in motor_control.cpp and motor_control.h.
    - Added keypad input handling in OpenScoutTransmitterCode for emergency commands.
    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
2026-02-05 Update HC-12 configuration to use Serial2; adjust command handling and wiring instructions
2026-02-09 Refactor WiFi initialization: defer connection handling to the monitoring task to prevent blocking in setup
    [OpenScoutArduinoCode.ino, wifi_manager.cpp]
2026-02-09 Add obstacle detection to motor control and implement ultrasonic sensor functions
2026-02-10 Added cad models
    [A2 aluminium.stl, Angle Bracket 2020.stl, BAse Plate.SLDPRT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]
2026-02-11 updated docs
    [BAse Plate.STL, Body1.STL, Body2.STL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]
2026-02-11 Remove mechanical assembly overview image from README.md
